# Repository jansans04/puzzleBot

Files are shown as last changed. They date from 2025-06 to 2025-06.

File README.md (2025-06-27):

# PuzzleBot
Aquest projecte ha estat desenvolupat dins de l'assignatura de Robòtica de la Universitat Autònoma de Barcelona. L’objectiu és construir un robot capaç de resoldre puzles de manera autònoma. El robot funciona de manera similar a una màquina CNC, però incorpora una ventosa i una bomba de succió que li permeten agafar i col·locar peces amb precisió.

# Taula de contingut
   * [Objectius](#Objectius)
   * [Funcionament del sistema](#Funcionament-del-sistema)
   * [Arquitectura del projecte](#Arquitectura-del-projecte)
   * [Materials i components](#Materials-i-components)
   * [Software](#Software)
   * [Instal·lació i us](#Instal·lació-i-us)
   * [Resultats](#Resultats)
   * [Treball futur / millores](#Treball-futur-/-millores)
   * [Autors](#Autors)

# Objectius
L’objectiu principal d’aquest projecte és dissenyar i construir un robot capaç de resoldre puzles de forma autònoma, identificant la posició de les peces i col·locant-les correctament sobre una base.

Per assolir aquest objectiu general, es plantegen els següents objectius específics:

Dissenyar i construir un sistema robòtic funcional amb moviment controlat en 2D (com una màquina CNC) que permeti desplaçar-se amb precisió dins d’un pla de treball.

Implementar un sistema de manipulació d’objectes, mitjançant una ventosa i una bomba de succió, per agafar i deixar anar peces amb fiabilitat.

Desenvolupar el programari de control del robot, incloent la generació de trajectòries i la gestió de la interacció amb els diferents components (motores, ventosa, sensors...).

Garantir la precisió i repetibilitat dels moviments, per assegurar que les peces del puzle es col·loquin correctament.

Integrar i provar el sistema complet, realitzant tests pràctics amb diferents puzles per validar-ne el funcionament i detectar possibles millores.

# Funcionament del sistema

El robot ha estat dissenyat per operar de manera similar a una màquina CNC, amb l’objectiu de col·locar peces de puzle amb precisió sobre una superfície de treball. El sistema combina moviment mecànic, components electrònics i control programat a través d’una Raspberry Pi. A continuació es detallen els diferents subsistemes:

## Sistema mecànic
Moviment en els eixos X i Y: S'aconsegueix mitjançant corretges dentades, rodaments i barres de ferro llises que proporcionen una base estable i precisa. L'eix X està accionat per dos motors pas a pas que treballen de manera sincronitzada, mentre que l'eix Y utilitza un únic motor pas a pas.

Eix Z (vertical): Controlat per un micromotor connectat a una rosca infinita, que permet elevar o baixar la ventosa amb precisió.

Rotació de peces: S’inclou un servomotor addicional que permet girar les peces abans de col·locar-les, assegurant que s’ajustin correctament a la seva posició final.

Sistema de succió: Format per una ventosa i una bomba de succió, permet agafar les peces de manera segura i controlar-ne la col·locació.

## Posicionament i referència
Per establir el punt d'origen del robot (coordenada 0,0), s’utilitzen dos sensors de final de cursa, un per a cada eix (X i Y). Aquests sensors permeten al sistema fer un calibratge inicial i garantir que tots els moviments posteriors siguin precisos i repetibles.

## Electrònica i control
Unitat de control principal: Una Raspberry Pi s’encarrega de gestionar el comportament global del robot, executant el programari que coordina els moviments, la succió i la rotació.

Controladors de motor: Cada motor pas a pas està connectat a un driver de control, alimentat mitjançant una font d'alimentació externa, que proporciona la potència necessària per al moviment estable i controlat dels eixos.

Interfície de control: El sistema pot rebre instruccions preprogramades per resoldre un puzle determinat, i l’arquitectura està pensada per permetre fàcilment una ampliació cap a un sistema més intel·ligent o interactiu.

## Visió artificial
El robot incorpora una càmera Pi connectada a la Raspberry Pi. Aquesta càmera s’utilitza per detectar la posició i orientació de les peces del puzle sobre la superfície de treball. Mitjançant tècniques bàsiques de processament d’imatge, el sistema pot identificar quines peces estan disponibles i on es troben, facilitant la seva manipulació de manera automatitzada.

# Arquitectura del projecte
L’arquitectura del projecte PuzzleBot està organitzada en diversos nivells funcionals que es comuniquen de forma coordinada per assolir l’objectiu final: resoldre un puzle de manera autònoma. Aquesta estructura modular permet dividir clarament les responsabilitats entre el maquinari, el programari i la interacció entre ambdós.

En el nivell físic, el sistema està format per una base mecànica que proporciona moviment precís en els eixos X, Y i Z, juntament amb un conjunt de dispositius per manipular les peces (ventosa, bomba de succió i servomotor de rotació). Aquests elements són accionats mitjançant controladors electrònics que responen a ordres directes de la Raspberry Pi, la qual actua com a cervell del robot.

El programari s'encarrega de coordinar les diferents accions del sistema. A partir d’una imatge inicial del puzle, s’aplica visió artificial per localitzar les peces i generar una seqüència d’accions per col·locar-les. Aquestes accions es transformen en moviments concrets, enviats des de la Raspberry Pi als diversos actuadors mitjançant els GPIO i els drivers corresponents.

A nivell d'integració, el sistema es basa en una arquitectura lineal i seqüencial, però deixa oberta la porta a futures ampliacions cap a sistemes més intel·ligents o paral·lels. Tots els components comparteixen una alimentació comuna i una referència espacial establerta mitjançant sensors de final de cursa, que permeten un calibratge automàtic i fiable.

En conjunt, l’arquitectura del PuzzleBot reflecteix una combinació entre precisió mecànica, simplicitat electrònica i flexibilitat programàtica, que facilita tant el desenvolupament com la futura extensió del projecte.

# Materials i components
A continuació es detallen els components utilitzats per a la construcció del robot, dividits en tres grans grups: electrònica, mecànica i altres elements auxiliars.

## Electrònica
3 × Motors pas a pas NEMA 17

- 2 per a l’eix X (muntats en paral·lel)

- 1 per a l’eix Y

1 × Micromotor DC amb reductora

- Utilitzat per controlar el moviment de l’eix Z mitjançant una rosca infinita

1 × Servomotor SG90 o similar

- Per girar les peces abans de col·locar-les

1 × Bomba de succió de 5V

- Per agafar i moure les peces mitjançant una ventosa

2 × Finals de cursa

- Per detectar el punt 0,0 (X i Y)

3 × Drivers de motors pas a pas (com A4988 o DRV8825)

1 × Font d'alimentació de 12V

- Per alimentar motors i bomba

1 × Raspberry Pi (model 3B, 4 o similar)

- Unitat de control principal

1 × Càmera Pi per Raspberry

- Per a la detecció de peces mitjançant visió artificial

Cables, connectors i protoboard

## Mecànica
Corretges dentades GT2 i politges

- Per transmetre el moviment als eixos X i Y

Barres llises de ferro o acer inoxidable

- Guies lineals per al moviment suau dels eixos

Rodaments lineals LM8UU i LM12UU

- Per reduir la fricció en el desplaçament

Rosca infinita i femella acoblada

- Per al moviment vertical de l’eix Z

Estructura de suport feta amb fusta

Peces impreses en 3D per incorporar els components

## Altres
Ventosa de silicona petita

Tubs de silicona per a la succió

Tornilleria, separadors i femelles

Base de treball

# Software  

La carpeta **`src/`** conté tot el codi; està organitzada en mòduls auto-contenuts.  

| Carpeta / Fitxer | Paper dins el sistema |
|---|---|
| **main.py** | Punt d’entrada de la Raspberry. Modes: online (`socket`) i offline (`plan.json`). |
| **control.py** | FSM central: llegeix plans, invoca `movement.py`, escolta `feedback.py` i envia estats al PC. |
| **movement.py** | Mòdul **Moviment**. Drivers dels 2 NEMA-17 (X), NEMA-17 (Y), 28BYJ-48 (Z), servo i bomba. Inclou rampes i homing. |
| **feedback.py** | Mòdul **Retroalimentació**. Fil que vigila finals de carrera, presòstat de buit i E-Stop; dispara callbacks al Control. |
| **planificació.py** | Mòdul **Planificació**. Construeix la llista de pick / place a partir de les matrius de l’estat inicial/final (greedy NN). |
| **configuracio.py** | **Paràmetres clàssics** dels motors (pins DIR/STEP, micro-stepping, pas d’husillo). El mantindrem per compatibilitat amb el codi antic. |
| **sockets/** | Comunicació Pi ↔ PC |
| ├─ `config.py` | Config global (*pins*, IP PC, paràmetres mecànics). Es pot sobreescriure amb variables d’entorn. |
| ├─ `socket_client_pi.py` | Client TCP (corre a la Pi). Envia `HELLO` i `STATUS`, rep `PLAN`. |
| └─ `socket_server_pc.py` | Servidor TCP (corre al PC). Rep `HELLO`, genera el plan amb els mòduls de visió/greedy, l’envia i monitora l’estat. |
| **vision/** | Mòdul **Percepció** (PC) |
| ├─ `main.py` | Pipeline complet de visió. |
| ├─ `segment_pieces.py` | Segmentació de peces amb OpenCV. |
| ├─ `normalize_pieces.py` | Normalitza imatges per al solver. |
| ├─ `solve_puzzle_borders.py` | Detecta contorn, orienta tauler. |
| ├─ `piezas_info.json` | Sortida: posició i angle actual de cada peça. |
| ├─ `solution_greedy.json` | Resultat del solver: posició final/rotació. |
| └─ carpetes `in/`, `out_piezas/`, `pieces/` | Entrades i sortides intermèdies de visió. |

**Flux resumit**

1. **Visió (PC)**: detecta peces ⇒ `solution_greedy.json`.  
2. **socket_server_pc.py**: tradueix a `PLAN` i l’envia a la Pi.  
3. **socket_client_pi.py**: rep `PLAN` i l’entrega a `control.py`.  
4. **control.py**: executa ordres amb `movement.py`, vigila `feedback.py`.  
5. Estat (`READY`, `DONE`, `FINISHED`, `ERROR`) torna al PC via socket.

Aquesta arquitectura modular permet canviar qualsevol bloc (visió, algoritme, mecànica) sense reescriure la resta del codi.

# Resultats

Aquest projecte ha representat un repte molt més gran del que inicialment imaginàvem. Tot i que l'objectiu semblava clar i assolible, el procés de disseny, construcció i integració del sistema ha resultat ser molt més complex, amb múltiples dificultats tant tècniques com logístiques.

Durant el desenvolupament ens hem trobat amb problemes inesperats: des d’errors mecànics i electrònics, fins a limitacions en la coordinació entre el maquinari i el programari. Això ens ha obligat a adaptar-nos constantment, buscar solucions creatives i modificar diversos aspectes del disseny inicial.

Tot i aquestes complicacions, estem molt satisfets amb el resultat final. El robot que hem aconseguit construir s’ajusta molt al que havíem plantejat al principi del projecte: és capaç de detectar peces, moure’s dins del pla de treball, manipular les peces amb la ventosa i col·locar-les correctament a la seva posició.

A més, hem pogut dur a terme els tests i les proves pràctiques que ens havíem proposat, i aquests han demostrat que el sistema és funcional i té una base sòlida per a futures millores. Més enllà del resultat tècnic, aquest projecte ha estat una experiència d’aprenentatge intens i realista sobre el treball en equip, la resolució de problemes i la integració de sistemes complexos.

# Dificultats i solucions
Al llarg del desenvolupament del projecte, ens hem trobat amb diversos reptes tant en la fase de disseny com en la d'integració i posada en marxa del robot. A continuació es descriuen les principals dificultats:

## Integració i disseny mecànic
Dimensions incorrectes: En una primera versió del disseny, les dimensions d'algunes peces no s’ajustaven correctament entre elles, cosa que va dificultar el muntatge i va provocar que haguéssim de redissenyar part de l’estructura per adaptar-la millor als components reals.

Sistema d’elevació amb rosca infinita: La construcció d’un sistema funcional per pujar i baixar l’eix Z va suposar una dificultat important. Després d’explorar diferents opcions, vam decidir dissenyar i imprimir en 3D un mecanisme amb rosca infinita, que finalment es va adaptar bé al sistema.

## Problemes electrònics
Micromotor trencat: Durant les proves, el micromotor encarregat de l’eix Z es va avariar, cosa que ens va obligar a buscar-ne un de substitut compatible i tornar a ajustar el muntatge.

Cables cremats i connexions defectuoses: Alguns cables es van sobreescalfar i fondre, provocant interrupcions en el subministrament d’energia o en la transmissió de senyals. Això ens va portar a revisar completament les connexions i substituir diversos cables.

Coordinació de motors: Aconseguir que tots els motors funcionessin simultàniament i de manera estable va ser un procés llarg. Vam tenir problemes tant amb el codi de control com amb l’alimentació elèctrica, que inicialment no era suficient per alimentar tot el sistema alhora.

# Autors
Nil Mazouzi More - NIU: 1674092

Jan Sans Domingo - NIU: 1673276

Noah Nelson Carcelen - NIU: 1637982

Mauri Marquès Soto - NIU: 1673948

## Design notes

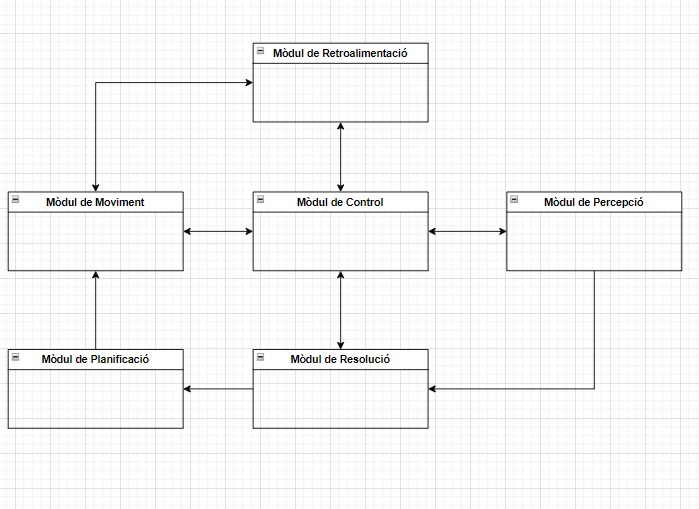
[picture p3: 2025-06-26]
img/foto moduls.jpg

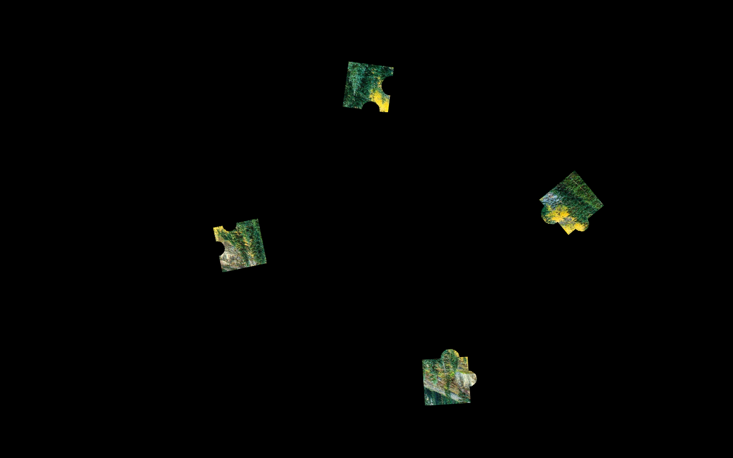
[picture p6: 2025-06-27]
src/vision/in/puzzle_con_piezas2x2.png

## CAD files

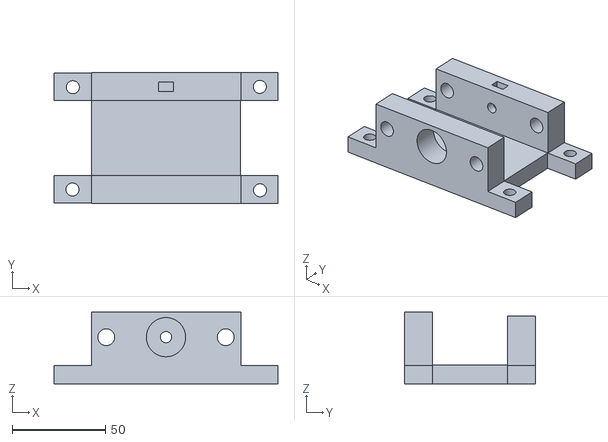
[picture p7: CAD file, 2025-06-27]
Peces 3D Robot/Peces 3D/Deslizador-Cuerpo.stl
120.0 x 70.0 x 38.4

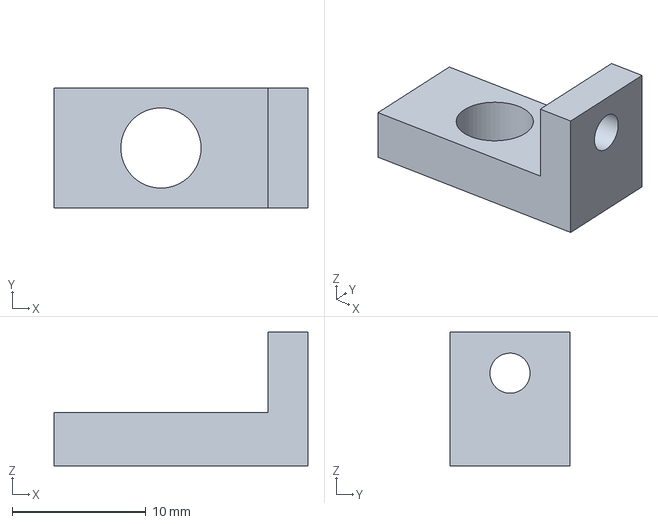
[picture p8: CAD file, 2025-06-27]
Peces 3D Robot/Peces 3D/Freecad/suport rodament.FCStd
19.0 x 9.00 x 10.0 mm

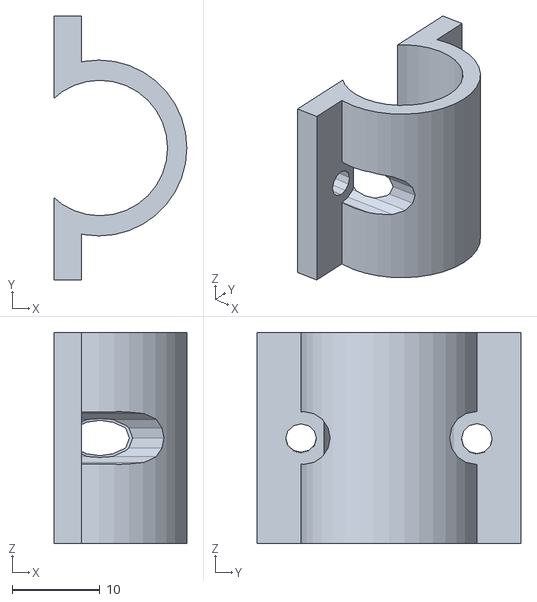
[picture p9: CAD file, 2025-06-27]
Peces 3D Robot/Peces 3D/SoportRodamentsPetits/soporte_del_rodamiento_lm8uu_a_la_arana_prusa_i3.stl
15.1 x 30.0 x 24.0

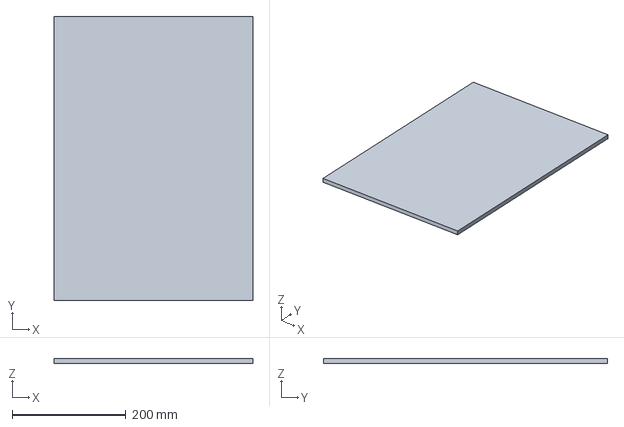
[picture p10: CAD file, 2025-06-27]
Peces 3D Robot/Peces Fusta/base.FCStd
350.0 x 500.0 x 9.00 mm

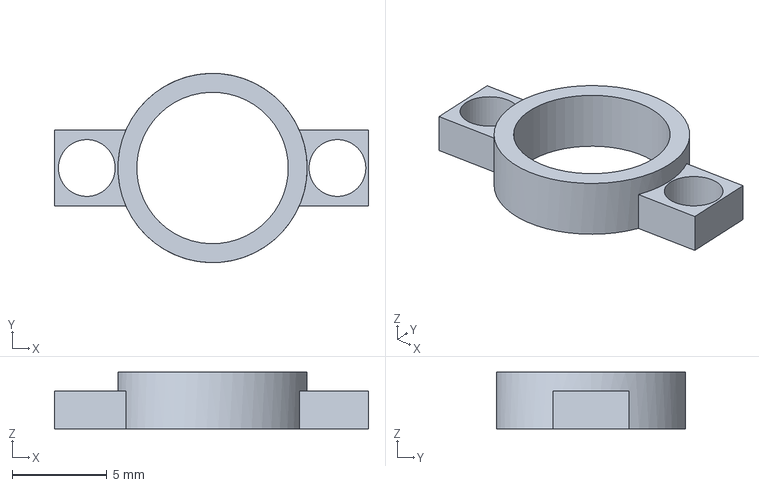
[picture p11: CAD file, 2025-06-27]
Peces 3D Robot/Peces 3D/Freecad/suport barres de ferro.FCStd
16.6 x 10.00 x 3.00 mm

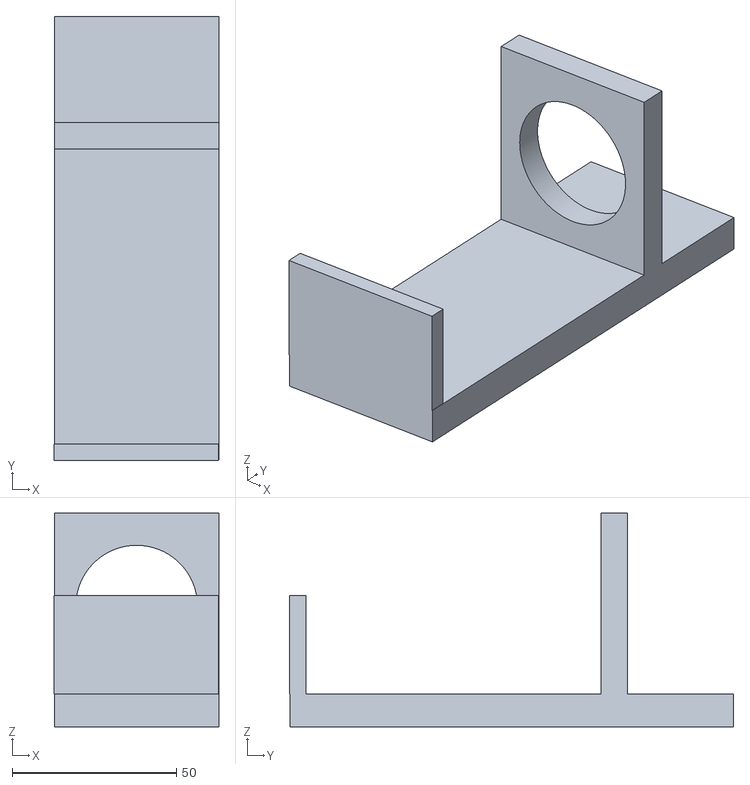
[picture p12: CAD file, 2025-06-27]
Peces 3D Robot/Peces 3D/Soport_motor_eix_Z-Body.stl
50.1 x 135.1 x 65.0

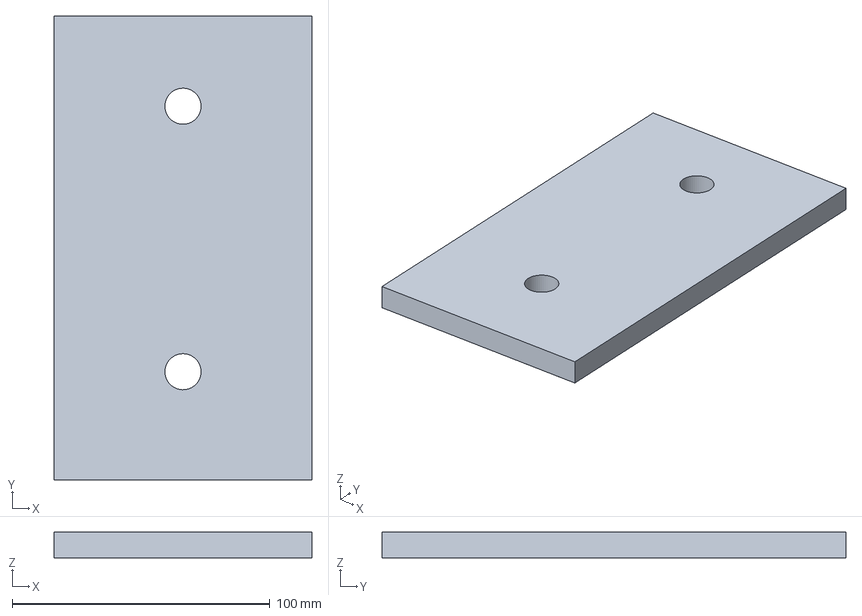
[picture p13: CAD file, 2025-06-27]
Peces 3D Robot/Peces Fusta/SUPORT EIX X x2.FCStd
100.0 x 180.0 x 10.0 mm

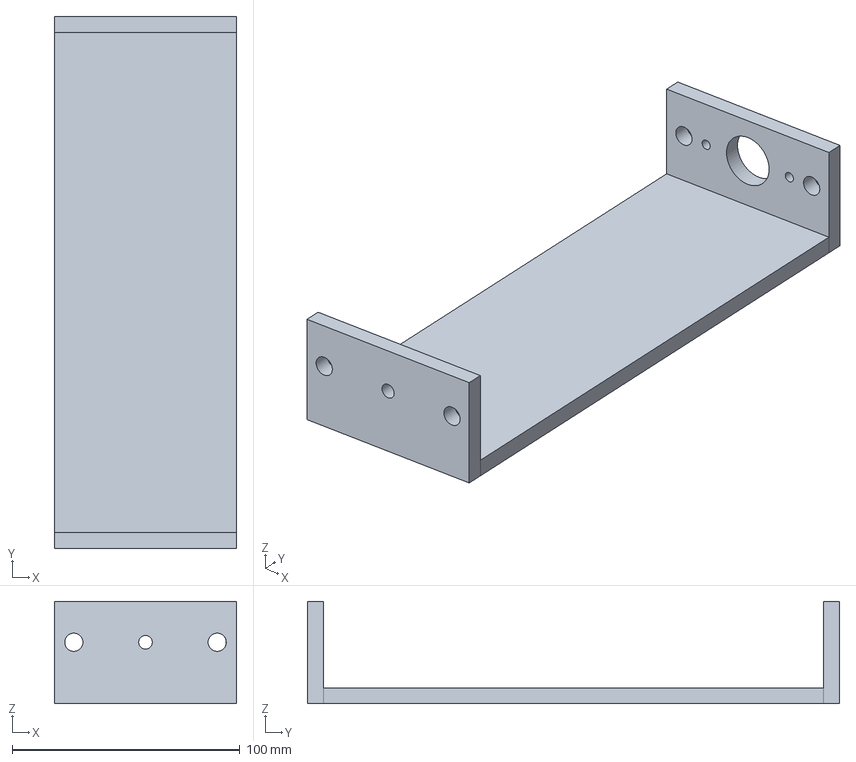
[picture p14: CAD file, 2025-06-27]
Peces 3D Robot/Peces 3D/Freecad/soport eix Z.FCStd
80.0 x 234.0 x 45.0 mm

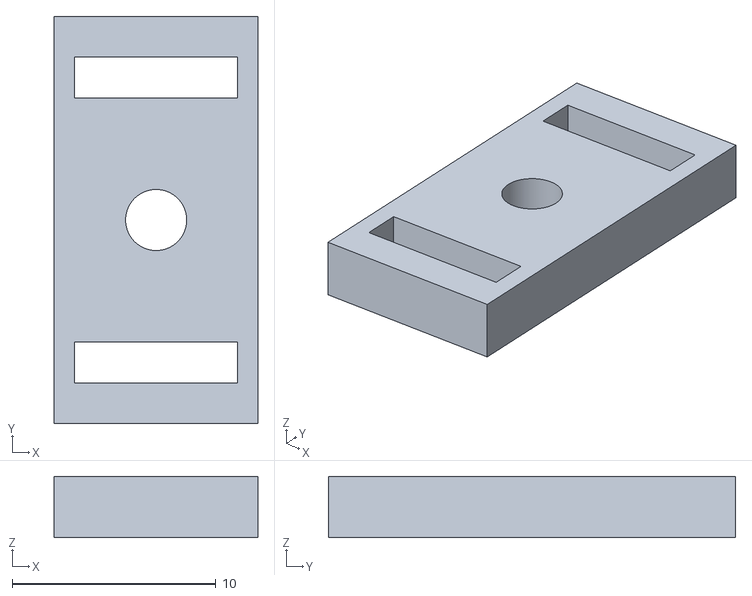
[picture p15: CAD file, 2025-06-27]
Peces 3D Robot/Peces 3D/Passdor corretga-Cuerpo.stl
10.0 x 20.0 x 3.00

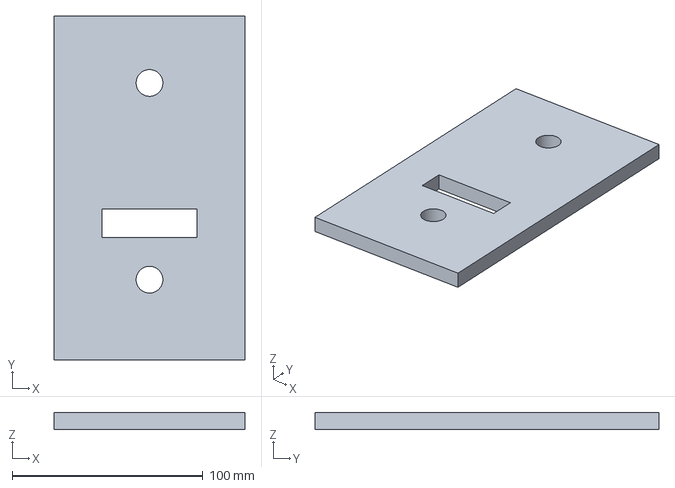
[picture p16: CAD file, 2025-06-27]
Peces 3D Robot/Peces Fusta/SUPORT EI X (per motor) x2.FCStd
100.0 x 180.0 x 9.00 mm

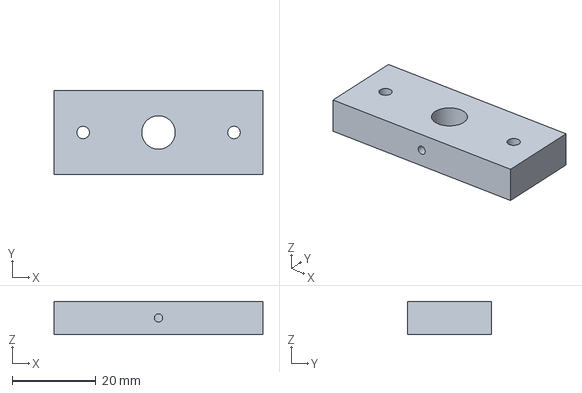
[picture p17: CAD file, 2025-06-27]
Peces 3D Robot/Peces 3D/Freecad/Soporte tubo peque.FCStd
50.0 x 20.0 x 8.00 mm

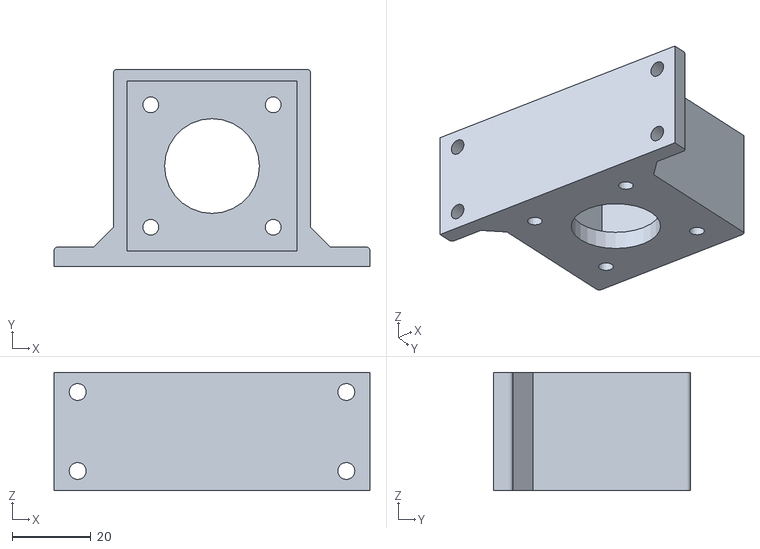
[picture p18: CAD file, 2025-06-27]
Peces 3D Robot/Peces 3D/soport nema 17-Nema17_Motor_Mount.stl
80.0 x 50.0 x 30.0

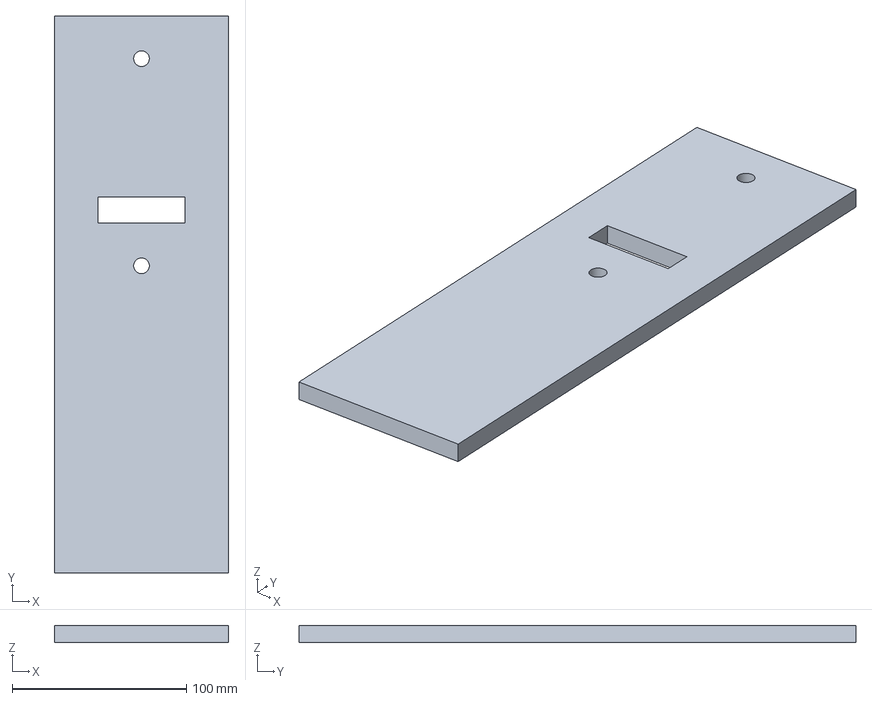
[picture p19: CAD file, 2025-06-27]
Peces 3D Robot/Peces Fusta/SUPORT EIX Y x2.FCStd
100.0 x 320.0 x 10.0 mm

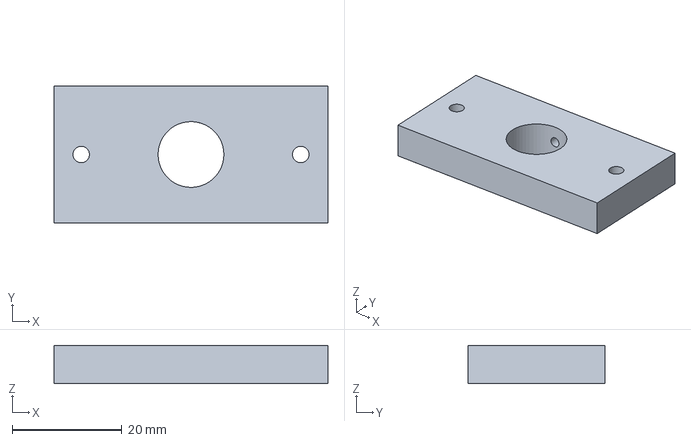
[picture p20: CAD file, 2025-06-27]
Peces 3D Robot/Peces 3D/Freecad/soporte tubo.FCStd
50.0 x 25.0 x 7.00 mm

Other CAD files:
Peces 3D Robot/Peces 3D/Freecad/Deslizador.FCStd
Peces 3D Robot/Peces 3D/soport eix Z-Cuerpo.stl
Peces 3D Robot/Peces 3D/tubo rotacio-Cuerpo.stl
Peces 3D Robot/Peces 3D/Freecad/Soport_motor_eix_Z.FCStd
Peces 3D Robot/Peces 3D/Freecad/Passdor corretga.FCStd
Peces 3D Robot/Peces 3D/Freecad/soport nema 17.FCStd
Peces 3D Robot/Peces 3D/Freecad/tubo rotacio.FCStd
Peces 3D Robot/Peces 3D/Soporte tubo peque-Body.stl
Peces 3D Robot/Peces 3D/soporte tubo-Cuerpo.stl

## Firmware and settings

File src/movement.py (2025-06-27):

#!/usr/bin/env python3
# movement.py ─ Mòdul de Moviment  • puzzleBot
# =========================================================
# Controla:
#   ▸ Dos NEMA-17 para eje X  (drivers STEP/DIR)
#   ▸ Un NEMA-17 para eje Y
#   ▸ Un 28BYJ-48 (ULN2003)   para eje Z
#   ▸ Bomba de vacío          (TB6612 o relé)
#   ▸ Servo SG-90/MG-90S      para rotación de pieza
#   ▸ 3 finales de carrera (X-, Y-, Z-) para homing
#
# Todas las constantes hardware se agrupan en CONFIG.
# =========================================================

from __future__ import annotations
import time
from dataclasses import dataclass
import RPi.GPIO as GPIO
from gpiozero import OutputDevice, DigitalInputDevice, PWMOutputDevice

# ──────────────────────────────────────────────────────────
# CONFIG ─ adapta SOLO este bloque a tu hardware
# ──────────────────────────────────────────────────────────
@dataclass
class CONFIG:
    # Eje X ─ 2 NEMA-17 en paralelo
    DIR_X1, STEP_X1 = 27, 17
    DIR_X2, STEP_X2 = 23, 22
    STOP_X_MIN      = 5          # normally-closed → GND cuando está “home”
    MICROSTEP_X     = 16
    PITCH_X_MM      = 8          # mm / vuelta del husillo

    # Eje Y ─ 1 NEMA-17
    DIR_Y, STEP_Y   = 6, 16
    STOP_Y_MIN      = 25
    MICROSTEP_Y     = 16
    PITCH_Y_MM      = 8

    # Eje Z ─ 28BYJ-48
    COILS_Z         = (8,7,12,13)   # IN1-IN4
    STOP_Z_MIN      = 24
    STEP_DELAY_Z    = 0.001         # s
    #                      32 × 64 / “full-step”  = 2048
    STEPS_REV_Z     = 2048

    # Servo
    SERVO_PIN       = 18
    SERVO_FREQ      = 50

    # Bomba ─ TB6612 (default)  • si usas relé activo-bajo, pon PUMP_USE_RELAY=True
    PUMP_USE_RELAY  = False
    PWMA, AIN1, AIN2, STBY = 19, 26, 20, 21   # puente-H
    RELAY_IN        = 4                       # solo si PUMP_USE_RELAY = True

    # Velocidades
    F_STEP_DELAY    = 0.0006     # delay base para aceleración (≈ 1.6 kHz máx)
    LIMIT_FREQ      = 0.00005    # retardo mínimo seguro (20 kHz máx)

# ──────────────────────────────────────────────────────────
GPIO.setmode(GPIO.BCM)
GPIO.setwarnings(False)

# ──────────────────────────────────────────────────────────
#                                                          #
#       CLASES DE ACTUADOR DE BAJO NIVEL                   #
#                                                          #
# ──────────────────────────────────────────────────────────
def _ramp_delay(step_idx: int, total: int, base: float, floor: float) -> float:
    """Perfil trapezoidal lineal: acelera mitad, frena mitad."""
    half = total // 2
    if step_idx < half:
        k = 1 - (step_idx / half)          # 1 → 0
    else:
        k = (step_idx - half) / half       # 0 → 1
    return floor + k * (base - floor)


class DualStepper:
    """Dos drivers STEP/DIR que deben moverse en paralelo (eje X)."""

    def __init__(self, dir_a, step_a, dir_b, step_b,
                 steps_per_mm: float,
                 stop_pin: int | None = None):
        self.dir_a, self.step_a = dir_a, step_a
        self.dir_b, self.step_b = dir_b, step_b
        for p in (dir_a, step_a, dir_b, step_b):
            GPIO.setup(p, GPIO.OUT, initial=GPIO.LOW)
        self.steps_per_mm = steps_per_mm
        self.stop = DigitalInputDevice(stop_pin, pull_up=True) if stop_pin else None

    # ───────────────────────────────────────
    def move_mm(self, mm: float):
        steps = int(abs(mm) * self.steps_per_mm)
        self.move_steps(steps, forward=mm > 0)

    def move_steps(self, steps: int, forward=True):
        GPIO.output(self.dir_a, GPIO.HIGH if forward else GPIO.LOW)
        GPIO.output(self.dir_b, GPIO.HIGH if forward else GPIO.LOW)
        for i in range(steps):
            d = _ramp_delay(i, steps, CONFIG.F_STEP_DELAY, CONFIG.LIMIT_FREQ)
            GPIO.output(self.step_a, GPIO.HIGH)
            GPIO.output(self.step_b, GPIO.HIGH)
            time.sleep(d)
            GPIO.output(self.step_a, GPIO.LOW)
            GPIO.output(self.step_b, GPIO.LOW)
            time.sleep(d)

    def home(self, backoff_mm: float = 2.0):
        if not self.stop:
            raise RuntimeError("No hay pin de stopper configurado.")
        # avance lento hasta que el stopper abra (recordar: NC → 1 cuando pulsa)
        GPIO.output(self.dir_a, GPIO.LOW)
        GPIO.output(self.dir_b, GPIO.LOW)
        while self.stop.value:  # 1 => NO pulsado
            GPIO.output(self.step_a, GPIO.HIGH)
            GPIO.output(self.step_b, GPIO.HIGH)
            time.sleep(0.002)
            GPIO.output(self.step_a, GPIO.LOW)
            GPIO.output(self.step_b, GPIO.LOW)
            time.sleep(0.002)
        # alejarse un poco
        self.move_mm(backoff_mm)


class SingleStepper:
    """Driver único STEP/DIR (eje Y)."""

    def __init__(self, dir_pin, step_pin, steps_per_mm, stop_pin=None):
        self.dir = dir_pin
        self.step = step_pin
        for p in (dir_pin, step_pin):
            GPIO.setup(p, GPIO.OUT, initial=GPIO.LOW)
        self.steps_per_mm = steps_per_mm
        self.stop = DigitalInputDevice(stop_pin, pull_up=True) if stop_pin else None

    def _pulse(self, delay):
        GPIO.output(self.step, GPIO.HIGH)
        time.sleep(delay)
        GPIO.output(self.step, GPIO.LOW)
        time.sleep(delay)

    def move_mm(self, mm: float):
        steps = int(abs(mm) * self.steps_per_mm)
        self.move_steps(steps, forward=mm > 0)

    def move_steps(self, steps: int, forward=True):
        GPIO.output(self.dir, GPIO.HIGH if forward else GPIO.LOW)
        for i in range(steps):
            d = _ramp_delay(i, steps, CONFIG.F_STEP_DELAY, CONFIG.LIMIT_FREQ)
            self._pulse(d)

    def home(self, backoff_mm=2):
        if not self.stop:
            raise RuntimeError("No hay pin stopper.")
        GPIO.output(self.dir, GPIO.LOW)
        while self.stop.value:
            self._pulse(0.002)
        self.move_mm(backoff_mm)


class BYJ48:
    """28BYJ-48 en full-step."""

    _SEQ = ((1,0,0,0),(0,1,0,0),(0,0,1,0),(0,0,0,1))

    def __init__(self, coil_pins: tuple[int,int,int,int], stop_pin: int):
        self.coils = [OutputDevice(p) for p in coil_pins]
        self.stop = DigitalInputDevice(stop_pin, pull_up=True)

    def _set_phase(self, ph):
        for c,v in zip(self.coils, ph): c.value = v

    def move_rev(self, rev: float, up=True):
        steps = int(rev * CONFIG.STEPS_REV_Z)
        seq   = self._SEQ if up else tuple(reversed(self._SEQ))
        for i in range(steps):
            self._set_phase(seq[i & 3])
            time.sleep(CONFIG.STEP_DELAY_Z)

    def home(self, backoff_rev=0.05):
        while self.stop.value:
            self._set_phase(self._SEQ[3])  # paso hacia abajo
            time.sleep(CONFIG.STEP_DELAY_Z)
        self.move_rev(backoff_rev, up=True)


class Servo:
    def __init__(self, pin: int):
        GPIO.setup(pin, GPIO.OUT)
        self.pwm = GPIO.PWM(pin, CONFIG.SERVO_FREQ)
        self.pwm.start(self._duty(90))

    @staticmethod
    def _duty(deg: float):
        return 2.5 + deg/180*10

    def rotate(self, deg: float):
        self.pwm.ChangeDutyCycle(self._duty(deg))
        time.sleep(0.8)


class Pump:
    def __init__(self):
        if CONFIG.PUMP_USE_RELAY:
            GPIO.setup(CONFIG.RELAY_IN, GPIO.OUT, initial=GPIO.HIGH)
        else:
            GPIO.setup(CONFIG.STBY, GPIO.OUT, initial=GPIO.LOW)
            GPIO.setup(CONFIG.AIN1, GPIO.OUT, initial=GPIO.LOW)
            GPIO.setup(CONFIG.AIN2, GPIO.OUT, initial=GPIO.LOW)
            self.pwm = PWMOutputDevice(CONFIG.PWMA, frequency=1000)

    def on(self):
        if CONFIG.PUMP_USE_RELAY:
            GPIO.output(CONFIG.RELAY_IN, GPIO.LOW)     # relé activo-bajo
        else:
            GPIO.output(CONFIG.STBY, GPIO.HIGH)
            GPIO.output(CONFIG.AIN1, GPIO.HIGH)
            GPIO.output(CONFIG.AIN2, GPIO.LOW)
            self.pwm.value = 1.0

    def off(self):
        if CONFIG.PUMP_USE_RELAY:
            GPIO.output(CONFIG.RELAY_IN, GPIO.HIGH)
        else:
            self.pwm.value = 0
            GPIO.output(CONFIG.STBY, GPIO.LOW)

# ──────────────────────────────────────────────────────────
#                                                          #
#           WRAPPER DE ALTO NIVEL                          #
#                                                          #
# ──────────────────────────────────────────────────────────
class MovementSystem:
    """Interface única para el resto del software (Control / Planner)."""

    def __init__(self):
        # Pasos/mm
        spmm_x = 200*CONFIG.MICROSTEP_X / CONFIG.PITCH_X_MM
        spmm_y = 200*CONFIG.MICROSTEP_Y / CONFIG.PITCH_Y_MM

        self.x = DualStepper(CONFIG.DIR_X1, CONFIG.STEP_X1,
                             CONFIG.DIR_X2, CONFIG.STEP_X2,
                             spmm_x, CONFIG.STOP_X_MIN)

        self.y = SingleStepper(CONFIG.DIR_Y, CONFIG.STEP_Y,
                               spmm_y, CONFIG.STOP_Y_MIN)

        self.z = BYJ48(CONFIG.COILS_Z, CONFIG.STOP_Z_MIN)
        self.servo = Servo(CONFIG.SERVO_PIN)
        self.pump  = Pump()

    # métodos de confort ------------------------------------
    def home_all(self):
        self.z.home()
        self.y.home()
        self.x.home()

    def move_xyz(self, dx_mm: float, dy_mm: float, dz_rev: float = 0.0):
        if dz_rev > 0:  self.z.move_rev(dz_rev, up=True)
        if dz_rev < 0:  self.z.move_rev(-dz_rev, up=False)
        if dx_mm:       self.x.move_mm(dx_mm)
        if dy_mm:       self.y.move_mm(dy_mm)

    # acciones pick & place ---------------------------------
    def pick(self):
        self.z.move_rev(2, up=False)
        self.pump.on()
        time.sleep(0.3)
        self.z.move_rev(2, up=True)

    def place(self):
        self.z.move_rev(2, up=False)
        self.pump.off()
        time.sleep(0.2)
        self.z.move_rev(2, up=True)

    # limpieza ----------------------------------------------
    def clean(self):
        GPIO.cleanup()
        print("GPIO limpio.")

# ──────────────────────────────────────────────────────────
#    AUTO-TEST INTERACTIVO
# ──────────────────────────────────────────────────────────
if __name__ == '__main__':
    bot = MovementSystem()
    try:
        print("Homing…")
        bot.home_all()

        while True:
            cmd = input("\nComando [x mm / y mm / up / dn / pick / place / servo deg / quit] > ").strip().lower()
            if cmd == "quit":
                break
            elif cmd.startswith("x"):
                bot.x.move_mm(float(cmd.split()[1]))
            elif cmd.startswith("y"):
                bot.y.move_mm(float(cmd.split()[1]))
            elif cmd == "up":
                bot.z.move_rev(1, up=True)
            elif cmd == "dn":
                bot.z.move_rev(1, up=False)
            elif cmd == "pick":
                bot.pick()
            elif cmd == "place":
                bot.place()
            elif cmd.startswith("servo"):
                bot.servo.rotate(float(cmd.split()[1]))
            else:
                print("Comando no reconocido.")
    except KeyboardInterrupt:
        pass
    finally:
        bot.clean()

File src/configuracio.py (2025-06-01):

# Pines GPIO
DIR_X1 = 23     # Dirección motor X1
DIR_X2 = 24     # Dirección motor X2 (si es independiente)
DIR_Y = 27      # Dirección motor Y

STEP_X1 = 18    # Paso motor X1
STEP_X2 = 25    # Paso motor X2 (si es independiente)
STEP_Y = 22     # Paso motor Y

# Configuración física (ajustar cuando sepas los valores reales)
PASOS_POR_MM_X = 400     # Ejemplo: 3200 pasos por vuelta / 8mm por vuelta
PASOS_POR_MM_Y = 400

# Delay entre pasos (controla velocidad)
STEP_DELAY = 0.001  # 1 ms entre flancos

# Microstepping configurado (opcional)
MICROSTEPPING = 16  # 1/16 de paso

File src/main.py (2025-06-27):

#!/usr/bin/env python3
"""
main.py  –  Entrypoint puzzleBot (Raspberry Pi)

▪ Sense arguments         → Mode ONLINE (socket amb el PC).
▪ --offline plan.json     → Executa el plan localment (tests).

Tots els paràmetres d’IP, ports, pins… es llegeixen de config.py.
"""

from __future__ import annotations
import argparse
import json
import sys
from pathlib import Path

from config   import CFG
from feedback import Feedback
from control  import ControlSystem
import socket_client_pi          # client online (ja implementat)

# ──────────────────────────────────────────────────────────
def run_offline(plan_file: Path):
    """Executa la llista de moviments sense necessitat de PC."""
    if not plan_file.exists():
        sys.exit(f"Plan {plan_file} no trobat")

    plan = json.loads(plan_file.read_text())

    fb   = Feedback()
    ctrl = ControlSystem(fb)     # Control rep un objecte Feedback

    # callbacks bàsics
    fb.on_estop = lambda: sys.exit(">>> E-STOP premut")
    fb.start()

    ctrl.queue.put(plan)         # encolem la llista sencera
    for status in ctrl.run_iter():
        print("[STATUS]", status)

    fb.close()
    print("Plan finalitzat OK")


def run_online():
    """Mode normal: connecta amb el PC i espera el plan."""
    socket_client_pi.main()      # delega tota la feina al client


# ──────────────────────────────────────────────────────────
if __name__ == "__main__":
    ap = argparse.ArgumentParser(
        description="PuzzleBot main – executa plans de moviment"
    )
    ap.add_argument("--offline", metavar="plan.json",
                    help="executa el plan localment, sense socket")
    args = ap.parse_args()

    try:
        if args.offline:
            run_offline(Path(args.offline))
        else:
            run_online()
    except KeyboardInterrupt:
        print("\nInterromput per l’usuari")
